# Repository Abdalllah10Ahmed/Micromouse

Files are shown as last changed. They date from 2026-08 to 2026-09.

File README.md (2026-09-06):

# Micromouse Robot — PCB Design Project

**🥈 2nd Place — IEEE ZSB RAS Chapter, PCB Design Track Final Project**

This project is a complete hardware and PCB design for a planned autonomous micromouse robot, developed end-to-end in Altium—from schematic and PCB layout through calculations and full engineering documentation—as the capstone project for the IEEE Zagazig Student Branch, Robotics & Automation Society chapter's PCB Design track.

---

## Overview

The robot must detect obstacles, plan its path, and adapt to a maze autonomously, while staying
within a strict **11cm × 11cm** PCB footprint. The design is split across **two stacked PCB
floors**, connected by a single 6-pin interconnect, to fit that size constraint while
physically separating noise-sensitive sensor circuitry from higher-current motor/power
circuitry — a deliberate noise-mitigation strategy baked into the architecture itself, not
patched on afterward.

> **Project scope:** This is a software-only PCB design project. It includes the schematics, component selection, PCB layout, routing, 3D modeling, and design verification. The board was not fabricated or assembled, and firmware development and physical maze testing were outside the scope of this PCB Design track.

## Full Schematic

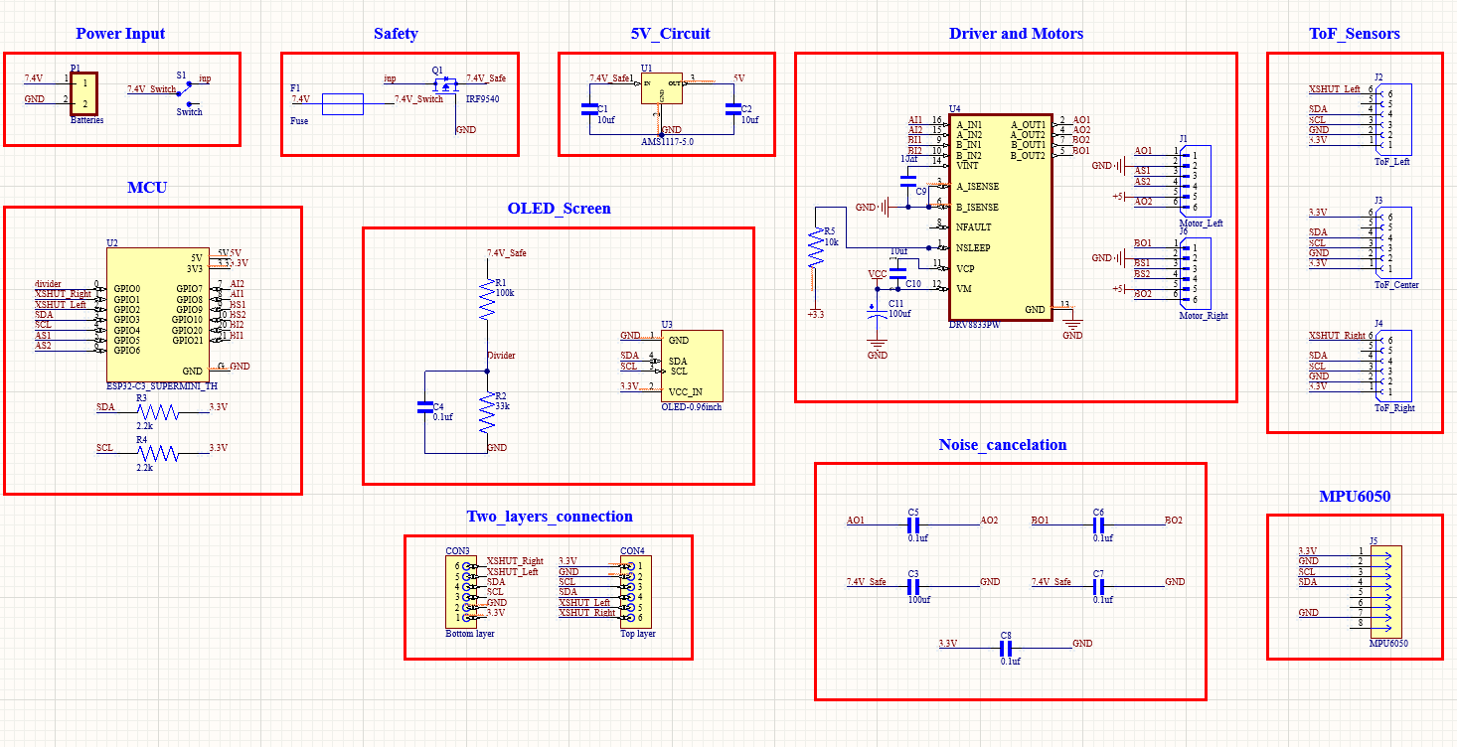
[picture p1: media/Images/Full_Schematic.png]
Full schematic overview


Ten functional blocks: Power Input, Safety (protection), 5V regulation, ESP32-C3 MCU, DRV8833
driver and motors, three ToF sensor headers, MPU6050, OLED display, motor-noise cancellation,
and the two-floor interconnect.

## Key Components

| Component | Role | Why This Part |
|---|---|---|
| ESP32-C3 Super Mini | Microcontroller | 13 usable GPIOs — an exact match to this design's requirement, ~3.8× smaller footprint than a standard 30/38-pin ESP32 DevKit |
| 3× VL53L0X | Time-of-Flight distance sensors (front/left/right) | Millimeter-accurate digital readings unaffected by wall color, smallest available package |
| MPU6050 | 6-axis IMU | Gyro yaw-rate feedback for confirming 90° turn completion |
| DRV8833 (bare IC) | Dual motor driver | HTSSOP-16 bare IC instead of breakout module — ~10-15× smaller footprint |
| 2× N20 micro gear motors | Drive + quadrature encoder feedback | 300mA stall current (datasheet-confirmed), encoder feedback for closed-loop turning |
| 0.96" OLED (SSD1306) | Status + battery percentage display | Shares the existing I2C bus — no extra pins |
| 2× 3.7V LiPo cells (series) | 7.4V, 1000mAh power source | Individually protected cells, charged separately |

## PCB Layout

| Top Floor (Sensors) | Bottom Floor (Power, MCU, Motor Driver) |
|---|---|
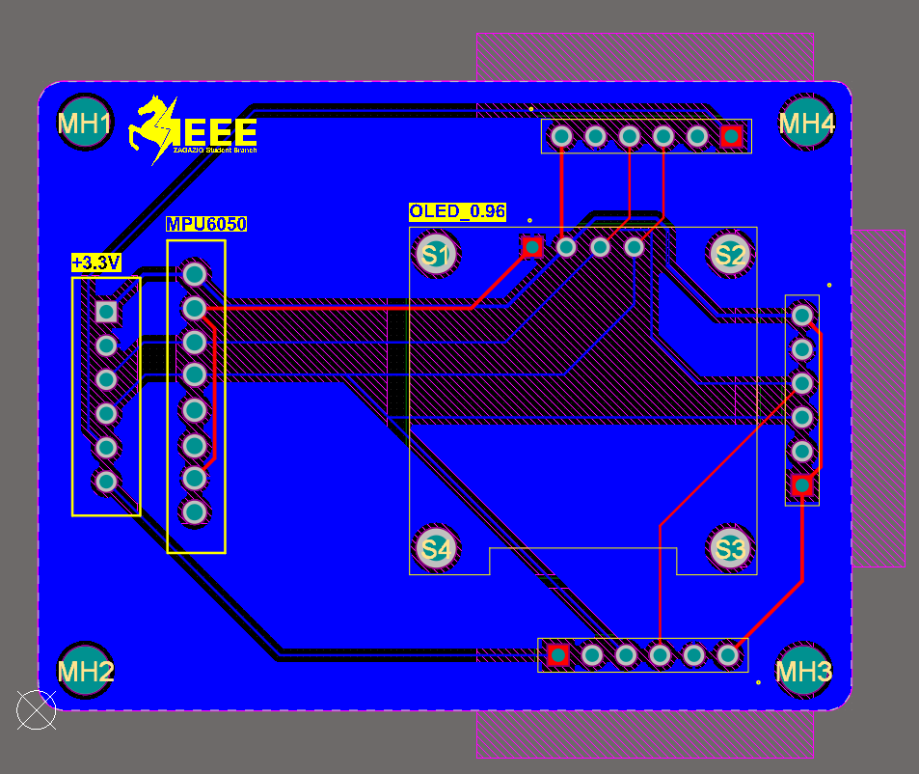
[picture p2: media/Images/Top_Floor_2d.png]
Top floor PCB layout
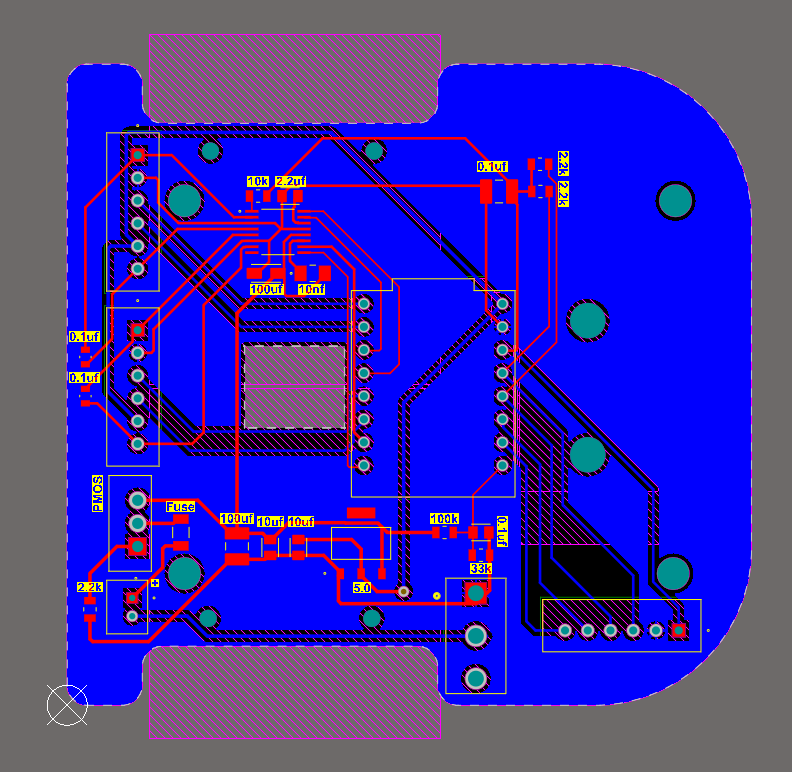
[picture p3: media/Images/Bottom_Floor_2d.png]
Bottom floor PCB layout
|  |  |

The bottom floor's motor mounting uses **edge notches cut directly into the board outline**,
letting each motor's gearbox body share vertical space with the PCB itself rather than hanging
entirely below it — reducing total stack height versus a conventional underneath-mounted motor.

## 3D Renders

<p align="center">
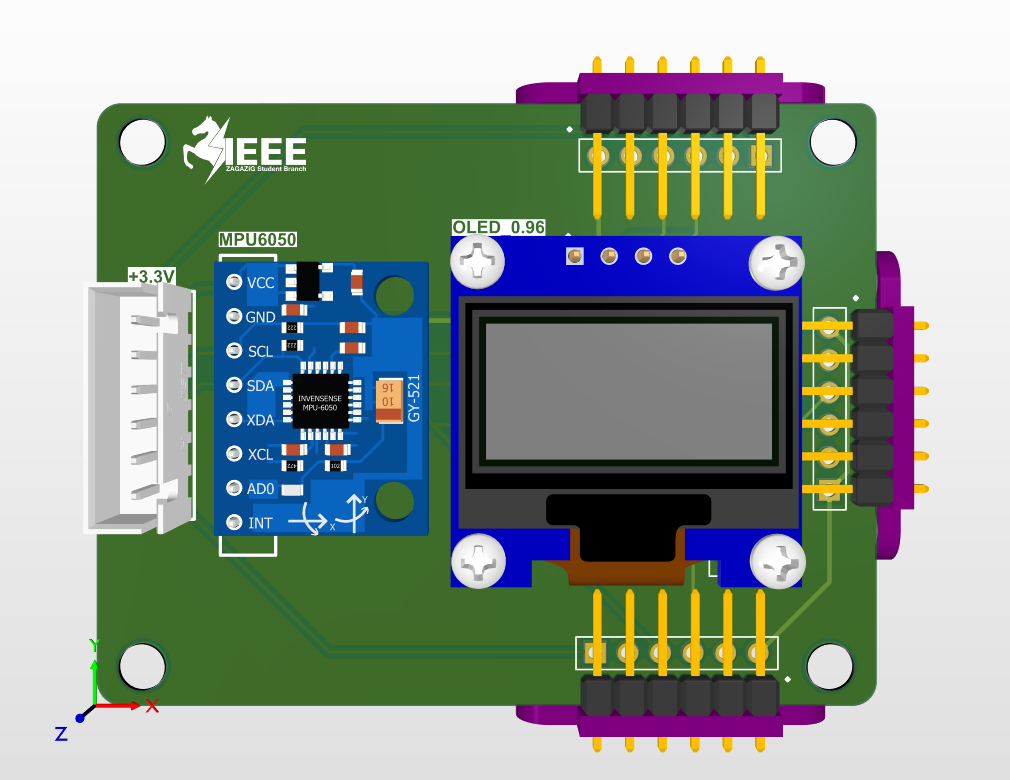
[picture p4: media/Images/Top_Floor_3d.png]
Top-floor PCB 3D render
  
  <br>
  <em>Top floor 3D render</em>
</p>

<p align="center">
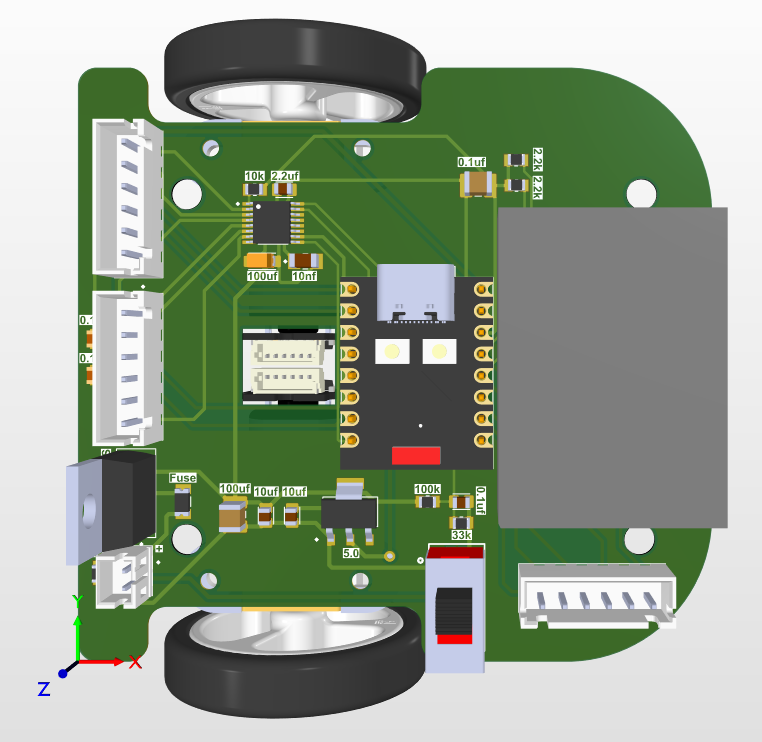
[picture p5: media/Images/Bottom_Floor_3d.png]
Bottom-floor PCB 3D render
  
  <br>
  <em>Bottom floor 3D render</em>
</p>

<p align="center">
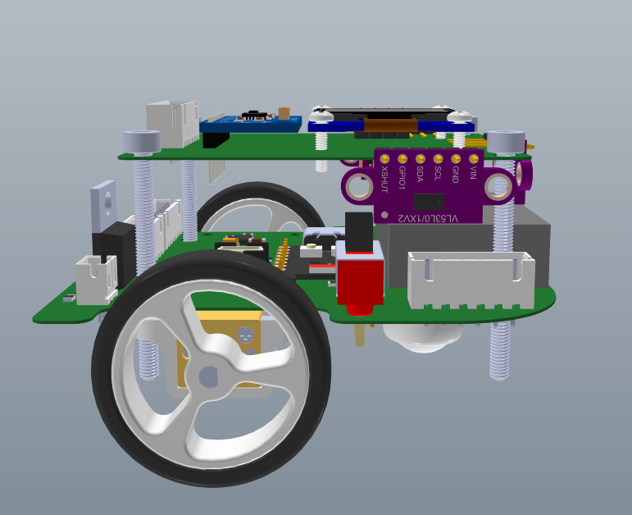
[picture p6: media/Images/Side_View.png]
Micromouse design side view
  
  <br>
  <em>Micromouse 3D render</em>
</p>

## Schematic Details

| MCU & Pin Assignment | Motor Driver & Noise Suppression |
|---|---|
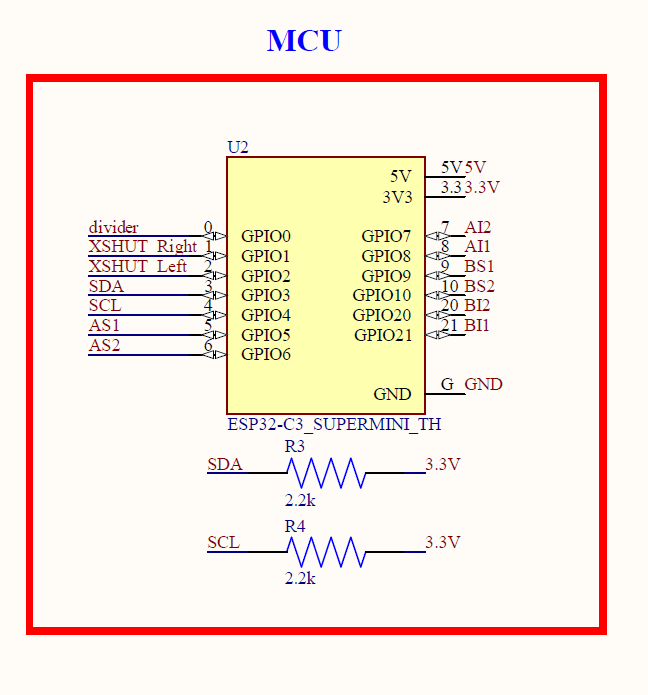
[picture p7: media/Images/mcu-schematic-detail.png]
MCU schematic
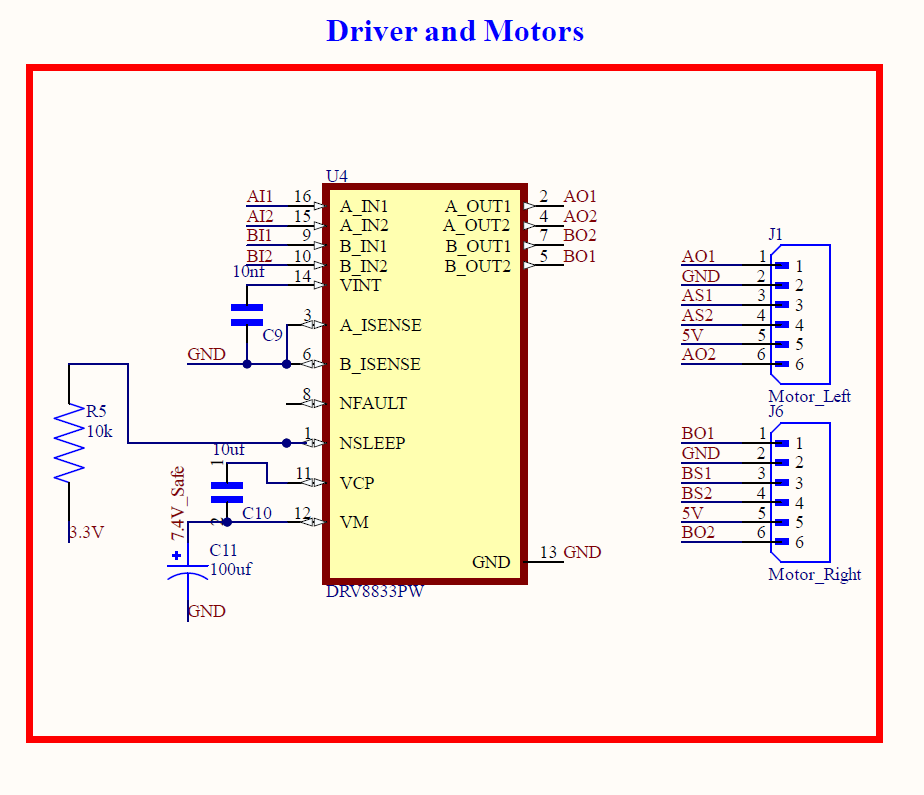
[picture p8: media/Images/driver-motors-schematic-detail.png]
Driver and motors schematic
|  |  |

## Architecture

- **I2C bus** shared by 5 devices (3× ToF, IMU, OLED). ToF sensors are individually addressed
  via XSHUT sequencing at boot — one sensor's XSHUT is hardwired to 3.3V and keeps the factory
  default address, while the other two are held in reset and reassigned unique addresses in
  firmware, saving a GPIO versus controlling all three.
- **Power chain:** Battery → fuse → reverse-polarity protection (P-channel MOSFET) → splits to
  the motor driver directly (bypassing regulation for efficiency) and to a 5V linear regulator
  for logic.
- **13/13 GPIO budget**, solved with zero spare pins: motor driver signals were deliberately
  assigned to the ESP32's BOOT-strapping pin (GPIO9) instead of encoder inputs, since a
  firmware-driven output can't glitch the boot sequence the way an unpredictable encoder input
  state could.
- **Noise mitigation:** motor suppression capacitors at the source, bulk + local decoupling at
  every IC, a solid ground plane on both floors, and the physical floor-split itself keeping
  the motor driver's switching noise away from the I2C bus and analog battery-sense line.

## Engineering Process — A Few Real Bugs We Caught

Documenting this honestly, since catching these was as much a part of the project as the final
design:

- **A net-label typo left the motor driver's sleep pin floating** (`+3.3` vs. `3.3V` — two
  different nets to Altium despite looking almost identical) — caught via ERC, not visual
  inspection.
- **Two DRV8833 support capacitor values were transposed** in the schematic (the charge-pump
  cap and the VINT bypass cap swapped values) — caught by cross-checking every value against
  the datasheet's specific requirements rather than just confirming a capacitor existed on each
  net.
- **A motor encoder signal was initially assigned to GPIO9** (the BOOT-strapping pin) — since
  an encoder's state at power-on is essentially random depending on wheel position, this could
  have caused intermittent boot failures. Reassigned to a motor-driver output pin instead.

## Repository Structure

```
hardware/   → Altium project (schematics, PCB layout, 3D)
docs/       → Bill of Materials, full calculations (trace widths, power budget,
              MCU justification, battery lifetime), presentation
media/      → Schematic/PCB/3D screenshots and project photos
```

## Documentation

- 📐 [Bill of Materials](docs/Micromouse_BOM.pdf)
- 🧮 [Calculations — Trace Width, Power, MCU Justification, Battery Lifetime](docs/Micromouse_Calculations.pdf)
- 🎞️ [Presentation](docs/Team_A.pdf)

## Verification

- ✅ Zero ERC errors, both schematic sheets
- ✅ Zero DRC errors, both PCB floors
- ✅ Every trace width calculated against the IPC-2221 standard with 2×–30× safety margin over
  the calculated minimum

## Contributors

| Member | Contribution |
|---|---|
| **Abdallah Ahmed** | Designed the top-floor sensor PCB and its routing; developed the complete schematic; reviewed and verified the design for correctness and cleanliness. |
| [Mohamed Hany](https://github.com/mohamed-hany123) | Designed the bottom-floor PCB, including the power, MCU, and motor-driver areas, and completed its routing. |

## Acknowledgments

Thank you to the IEEE ZSB RAS chapter leadership for the guidance and structure throughout this
track, and to everyone who made this competition possible.

## Usage and Permissions

Copyright © 2026 Abdallah Ahmed and Mohamed Hany. All rights reserved.

This repository is shared for portfolio and reference purposes only. No permission is granted to copy, modify, redistribute, fabricate, or commercially use any part of this project without prior written permission from the authors.

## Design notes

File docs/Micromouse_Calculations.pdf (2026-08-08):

# Micromouse

## Final Project — Calculations & Justification

IEEE ZSB · RAS Chapter — PCB Design Track Final Project

## 1 PCB Copper Trace Width Calculations

## 2 Power Calculations of All Components

## 3 Microcontroller Selection Justification

## 4 Battery Lifetime Calculations

## 1 PCB Copper Trace Width Calculations

Calculated using the IPC-2221 standard for external (top/bottom layer) traces, 1oz/ft² copper, 10°C allowable temperature rise.

## Area (mils²) = (I / (k × ∆T

0.44))⁽¹/0.725)

## | Width (mils) = Area / 1.37

I = current (A), ∆T = 10°C, k = 0.048.

## 1.1 — Top Floor (Sensors)

Net | Worst-Case I | Calc. Min. | Implemented | Margin
3.3V / GND (power) | 0.139 A | 0.020 mm | 0.3533 mm | 17.7×
Signal traces (SDA, SCL, XSHUT) | < 10 mA | < 0.01 mm | 0.25 mm | Ample

## 1.2 — Bottom Floor (Power, MCU, Motor Driver)

Net | Worst-Case I | Calc. Min. | Implemented | Margin
Main power rail (Fuse → Switch → Protection → VCC) | 0.789 A | 0.218 mm | 0.4 mm | 1.83×
DRV8833 VM | 0.600 A | 0.149 mm | 0.4 mm | 2.68×
Motor outputs → Motor Left / Right (each) | 0.300 A | 0.057 mm | 0.25 mm | 4.39×
Regulator path (7.4V_Safe → AMS1117 → 5V → ESP32) | 0.189 A | 0.030 mm | 0.4 mm | 13.3×
Signal traces (motor control, encoders, ADC divider) | < 10 mA | < 0.01 mm | 0.254 mm | Ample

## 2 Power Calculations of All Components

Calculated using P = V × I at each component's actual operating voltage.

Component | V | I (typ.) | P | Source
ESP32-C3 (active, radios off) | 3.3V | 45 mA | 0.149W | Espressif datasheet
3× VL53L0X ToF (30mA ea.) | 3.3V | 90 mA | 0.297W | ST datasheet
MPU6050 IMU | 3.3V | 3.6 mA | 0.012W | InvenSense datasheet
OLED 0.96in (SSD1306) | 3.3V | 20 mA | 0.066W | Manufacturer datasheet
2× Encoders (10mA ea., estimated) | 3.3V | 20 mA | 0.066W | Estimated
DRV8833 quiescent | 3.3V | 5 mA | 0.017W | Typical
AMS1117-5.0 quiescent | 7.4V | 5 mA | 0.037W | Typical
Battery divider bleed (100k+33k) | 7.4V | 0.056 mA | 0.0004W | Calculated
Q1 (IRF9540) loss — idle | — | @ 0.189A | 0.007W | Rds(on)=0.20Ω
Q1 (IRF9540) loss — typical | — | @ 0.439A | 0.039W | Rds(on)=0.20Ω
Q1 (IRF9540) loss — worst-case | — | @ 0.789A | 0.125W | Rds(on)=0.20Ω
2× N20 motors — typical (estimated) | 7.4V | 250 mA | 1.850W | ~40% of stall
2× N20 motors — worst-case stall | 7.4V | 600 mA | 4.440W | Manufacturer datasheet

## System Totals

Every regulation stage (AMS1117, Super Mini onboard regulator) is linear, not switching — current is approximately conserved through each stage rather than reduced, so every downstream component's current is reflected directly in what the battery must supply.

Scenario | Total Current | Total Power | Q1 Loss Share
Logic + sensors only (motors idle) | 189 mA | 1.399 W | 0.5%
Typical driving (motors normal) | 439 mA | 3.249 W | 1.2%
Worst-case (both motors stalled) | 789 mA | 5.839 W | 2.1%

## 3 Microcontroller Selection Justification

## Chosen microcontroller: ESP32-C3 Super Mini

Required: 4 motor-driver control pins, 4 quadrature encoder channels, a 2-pin I2C bus shared by 5 devices, 2 GPIO-controlled ToF address lines, and 1 ADC pin for battery sensing — 13 GPIOs total.

## 3.1 — ESP32-C3 Super Mini vs. a Standard 30/38-pin ESP32 DevKit

Spec | ESP32-C3 Super Mini | Standard 30/38-pin DevKit
Board footprint | 22.5 × 18 mm = 405 mm² | ~55 × 28 mm = 1,540 mm² (~3.8× larger)
CPU | Single-core RISC-V | Dual-core Xtensa LX6 (higher idle draw)
Onboard extras | Small onboard 3.3V LDO only | USB-UART bridge chip + large USB connector + full regulator
Usable GPIOs | 13 (exact match) | 30-38 (17-25 unused in this design)
Mounting | Pluggable, small 2.54mm header | Larger socket footprint or permanent solder-down
- 405mm² footprint is ~3.8× smaller than a standard DevKit's ~1,540mm² — a direct, quantifiable contribution to the 11×11cm limit and smallest-robot bonus
- A DevKit's onboard USB-UART bridge and full-size USB connector exist only for plug-and-program convenience — functionality this design moves off-board by programming the Super Mini externally before mounting, making that circuitry pure dead weight here
- 13 GPIOs is an exact match to this design's requirement; a 30/38-pin DevKit would leave 17-25 pins permanently unused
- Both chip families include WiFi/BLE by default; since this design uses neither, the smaller/cheaper C3 package is strictly better with no functional trade-off

## 3.2 — Handling the Tight Pin Budget Safely

- GPIO9 (BOOT button pin) carries only a motor-driver output signal, never an encoder input — a driver output is always actively set by firmware and cannot glitch the boot sequence the way an unpredictable encoder state could
- GPIO8 (onboard status LED) is assigned to a non-critical encoder channel — the LED flickering with wheel rotation is cosmetic only

## 4 Battery Lifetime Calculations

## Final Battery Specification

Spec | Value
Type / configuration | 2× 3.7V LiPo cells (ECOCELL) in series = 7.4V nominal
Capacity | 1000 mAh
Dimensions (per cell) | 35 × 25 × 10 mm
Weight (per cell / pair) | 22g / 44g total
Max charge current | 500 mA (0.5C) — per cell, charged individually
Max discharge current | 1000 mA (1C) max; 500 mA (0.5C) recommended continuous
Protection | Built-in per-cell: overcharge, over-discharge, short-circuit

## Step 1 — Runtime at Typical Operating Current

## Runtime (h) = Capacity (Ah) / Current (A)

Runtime = 1.0 Ah / 0.439 A ≈ 2.28 hours (~137 minutes).

## Step 2 — Runtime at Worst-Case Current

Runtime = 1.0 Ah / 0.789 A ≈ 1.27 hours (~76 minutes) — both motors permanently stalled; pessimistic-case only.

## Step 3 — Discharge Rate Check

This battery specifies fixed discharge limits: 500mA recommended continuous, 1000mA absolute maximum. Typical current (439mA) stays under the recommended limit; worst-case current (789mA) exceeds it by 58% but remains under the 1000mA absolute maximum — acceptable for this short-duration competition project.

## Step 4 — Practical Safety Margin for Competition Use

## Required capacity = Current × Runtime needed × 1.25

For a 15-minute session: 0.439A × 0.25h = 0.110 Ah, ×1.25 ≈ 137 mAh minimum. The chosen 1000mAh pack provides over 7× this minimum.

## Step 5 — Charging Procedure

Two independently-protected single cells, not one factory 2S pack — charge each cell individually: disconnect the series link, charge each 3.7V cell separately through its own JST-PH connector at or under 500mA, then reconnect in series for use.

Prepared for IEEE ZSB · RAS chapter - PCB Design track | Final Project: Micromouse

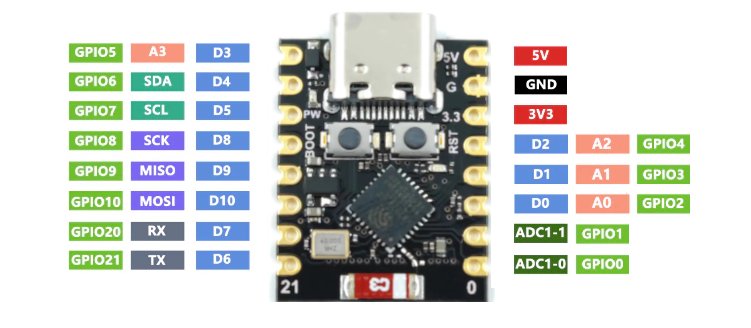
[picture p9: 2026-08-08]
media/Images/ESP32-C3 Super Mini- pinout.jpeg

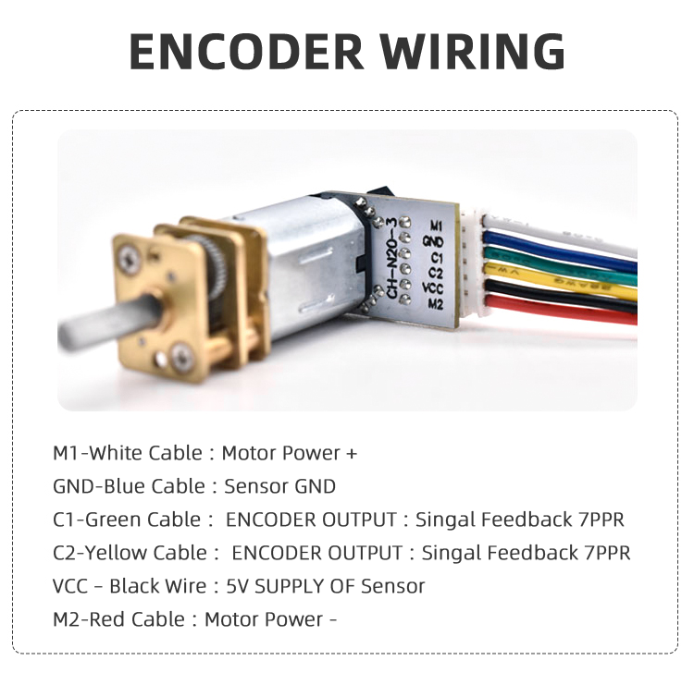
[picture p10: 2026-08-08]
media/Images/wires_encoder.png

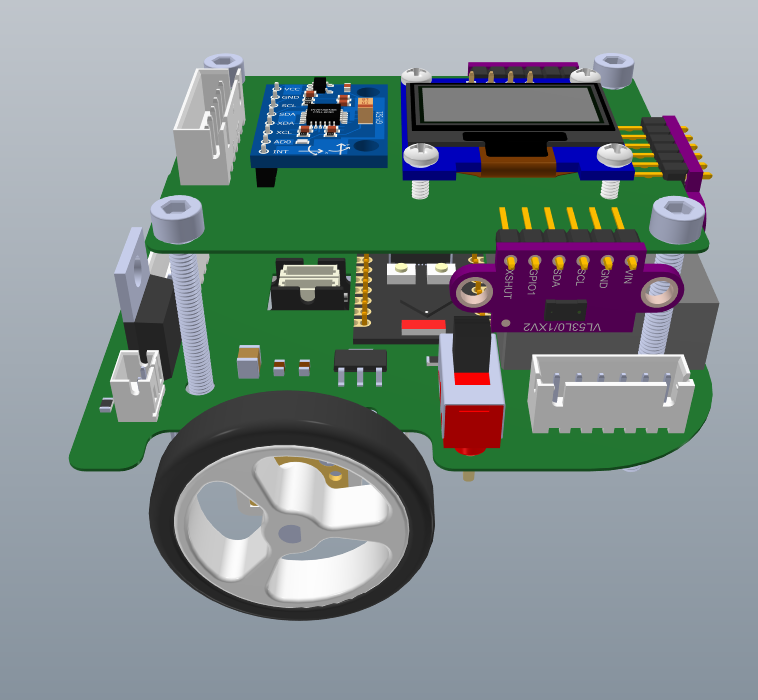
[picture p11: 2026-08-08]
media/Images/3D_View.png

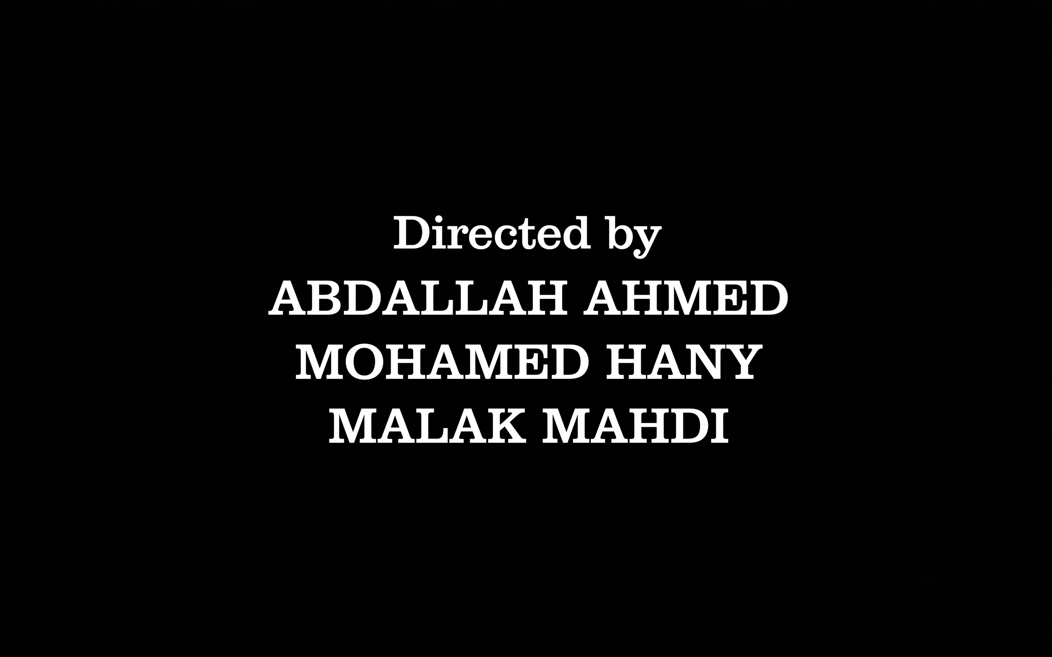
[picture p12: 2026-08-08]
media/Images/last slide.png

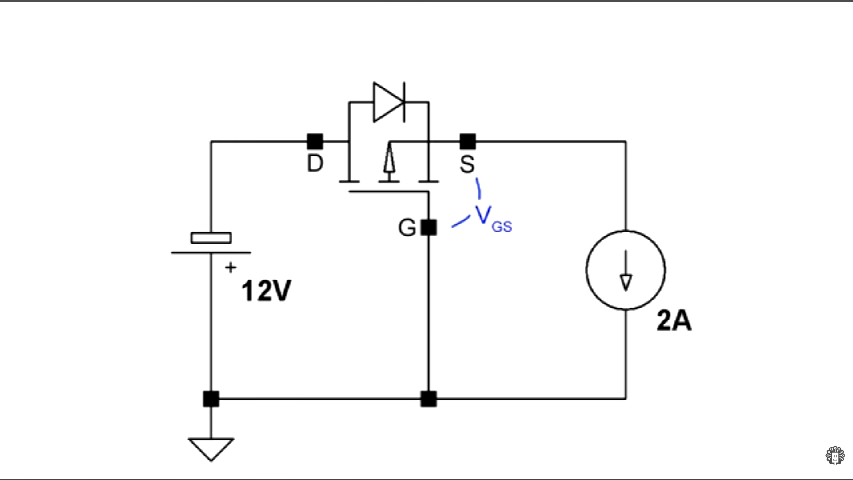
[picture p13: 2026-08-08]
media/Images/Reverse Polarity Protection.png

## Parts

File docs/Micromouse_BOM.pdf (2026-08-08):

Component | Store Link
VL53L0X ToF Distance Sensor (×3) | https://microohm-eg.com/gy-53-vl53l0x-laser-tof-flight-time-ranging-sensor-module-high-precision-time-of-flight-distance-measurement-with-pwm-serial-output/
MPU6050 IMU — GY-521 Breakout (×1) | https://makerselectronics.com/product/mpu-6050-imu-sensor-module-with-6-dof-gyroscope-accelerometer/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
OLED Display 0.96" SSD1306 (×1) | https://makerselectronics.com/product/oled-display-i2c-4-pin-0-96%E2%80%B3-2/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
Resistor 2.2kΩ, SMD 0805 (×2) | https://makerselectronics.com/product/chip-resistor-smd-2-2k%cf%89-%c2%b11-0-125w-%c2%b1100ppm-%e2%84%83-0805/
Resistor 100kΩ, SMD 0805 (×1) | https://makerselectronics.com/product/chip-resistor-smd-100k%cf%89-%c2%b11-0-125w-%c2%b1100ppm-%e2%84%83-0805/
Resistor 33kΩ, SMD 0805 (×1) | https://makerselectronics.com/product/chip-resistor-smd-33k%cf%89-%c2%b11-0-125w-%c2%b1100ppm-%e2%84%83-0805/
Resistor 10kΩ, SMD 0805 (×1) | https://makerselectronics.com/product/chip-resistor-smd-10k%CF%89-%C2%B15-0-125w-%C2%B1100ppm-%E2%84%83-0805/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
6-pin JST Connector, JST-PH 2.0mm (×4) | https://makerselectronics.com/product/b6b-xh-a-jst-xh-6-pin-header-2-5mm/
M3 Standoff / Spacer (×4) | https://www.ram-e-shop.com/ar/shop/spacer-cupper-15mf-copper-pcb-spacer-15mm-m-f-6291?category=121
M3 Screw + Nut (×4) | https://www.ram-e-shop.com/ar/shop/spacer-cupper-15mf-copper-pcb-spacer-15mm-m-f-6291?category=121
2-pin JST Connector, JST-PH 2.0mm (×1) | https://makerselectronics.com/product/b2b-xh-a-jst-xh-2-pin-header-2-5mm/
Fuse — PTC Resettable, SMD 1206 (×1) | https://makerselectronics.com/product/resettable-fuses-ptc-6v-1-1a-wt-1206-110-smd/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
Switch — SPDT Slide Switch (×1) | https://makerselectronics.com/product/slide-switch-3-pin-on-off-spdt/
MOSFET — IRF9540, P-channel, TO-220 (×1) | https://makerselectronics.com/product/irf9540-p-channel-power-mosfet-transistor-to-220-100v-19a-0-20%CF%89/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
Voltage Regulator — AMS1117-5.0, SOT-223 (×1) | https://makerselectronics.com/product/goodwork-ams1117-5-70db120hz-1a-fixed-5v-positive-18v-sot-223-dropout-regulators-smd/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
Capacitor 10µF, SMD 0805 (×4) | https://uge-one.com/product/smd-chip-ceramic-capacitor-size-0805-10uf/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
Capacitor 0.1µF, SMD 0805 (×6) | https://uge-one.com/product/smd-chip-ceramic-capacitor-size-0805-100nf/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
Capacitor 2.2µF (6.3V), SMD (×2) | https://makerselectronics.com/product/multilayer-ceramic-capacitors-mlcc-smd-smt-2-2uf-%c2%b110-50v-0805/
Capacitor 0.01µF / 10nF (16V), SMD (×2) | https://uge-one.com/product/smd-chip-ceramic-capacitor-size-0805-10nf/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
ESP32-C3 Super Mini (×1) | https://makerselectronics.com/product/esp32-c3-super-mini-development/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
Motor Driver IC — DRV8833PWP, HTSSOP-16 (×1) | https://makerselectronics.com/product/drv8833-2-channel-dc-motor-driver/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
N20 Micro Gear Motor w/ Encoder — JGA12-N20 (×2) | https://makerselectronics.com/product/jga12-n20-micro-metal-gear-dc-motor/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
LiPo Battery Cell — ECOCELL 3.7V 1000mAh (×2) | https://store.fut-electronics.com/products/3-7v-rechargeable-polymer-lithium-ion-battery-ecocell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
Metal Caster Wheel (x1) | https://uge-one.com/product/caster-wheel-small/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
M2 Screw (×8) | https://microohm-eg.com/screw-m2-2mm-x-12mm-with-nut/
M2 Nuts (x8) | https://microohm-eg.com/screw-nut-m2-2mm-1pcs/
N20 Motor Mount Bracket | https://makerselectronics.com/product/n20-motor-mount-bracket/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
N20 Rubber wheel | https://microohm-eg.com/n20-44mm-miniq-rubber-wheel-for-n20-gear-motor/
Capacitor 100µF (6.3V), SMD (×1) | https://makerselectronics.com/product/multilayer-ceramic-capacitors-mlcc-smd-smt-6-3v-100uf-x5r-%C2%B120-1206/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

### Micromouse Final Project — Bill of Materials

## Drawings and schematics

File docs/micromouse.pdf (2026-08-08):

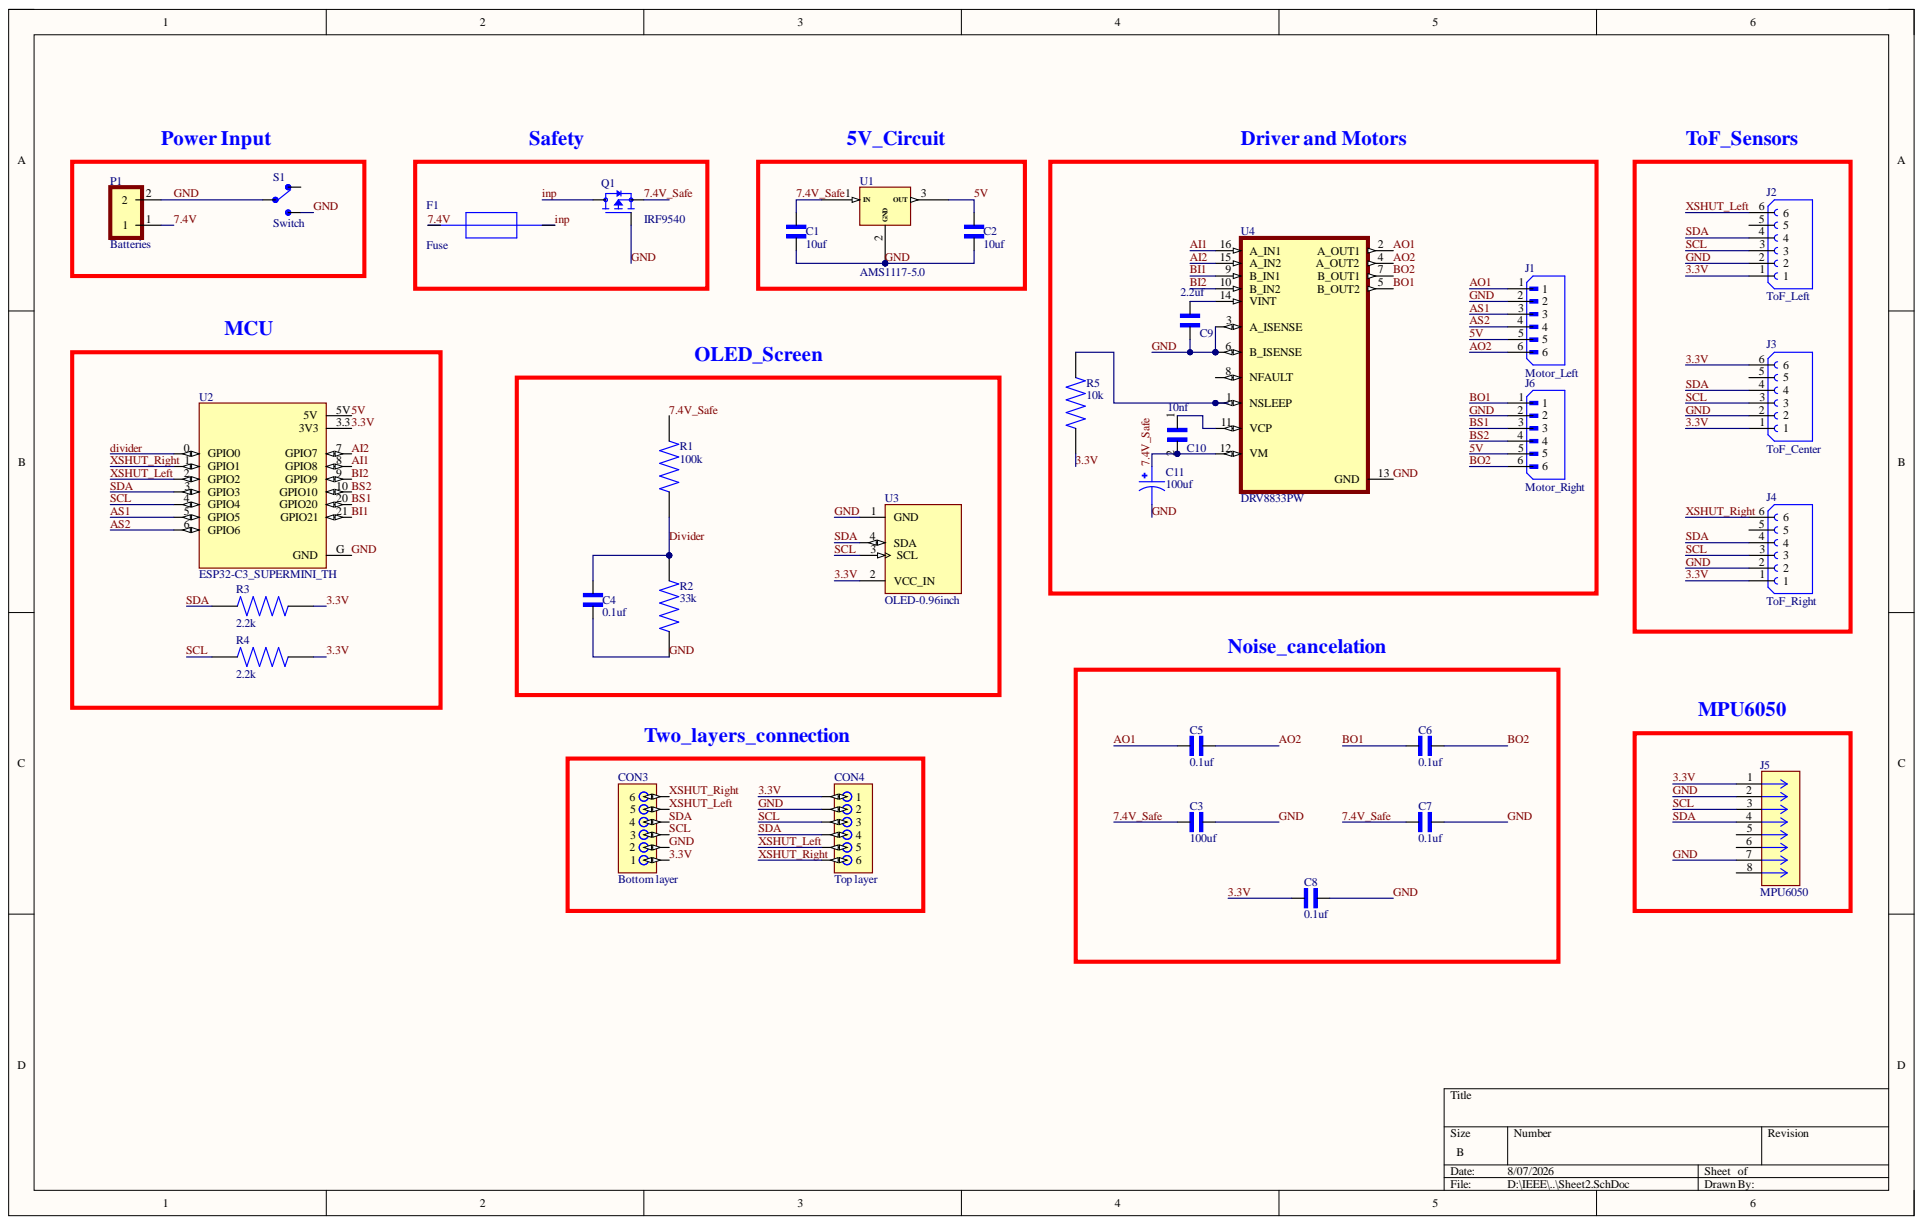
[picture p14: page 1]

Si z e | Num b er | Revi s i on

e : 8/07/ 20 2 6 | Sheet of
Fi l e : D : \IE E E \..\Sheet2.SchD o c | D rawn By:
